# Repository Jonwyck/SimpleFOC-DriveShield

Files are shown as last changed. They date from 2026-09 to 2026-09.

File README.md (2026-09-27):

> Fork additions: [v1.8 pinout and jumper guide](Design/DriveShield_pinout.org), [HTML guide](Design/DriveShield_pinout.html), and [initial KiCad 10 import](KiCad/README.org). The KiCad copy needs ERC/DRC and library/linkage cleanup before fabrication. Original EasyEDA design files remain unchanged.

# *Simple**FOC*** ***Drive**Shield* *v1.8*

 
 



This is an open-source low-cost BLDC driver boards in the form of a Arduino shield. It is a part of the *Simple**FOC*** project. The board is the big brother of the *Simple**FOC**Shield* and is designed to drive motors with higher current requirements, up to 40Amps. The board is created with the same philosophy as the *Simple**FOC**Shield* - to be simple to use, low-cost, and open-source and fully compatible with the *Simple**FOC***library. 

Additionally the aim of the board is to serve as a template project for the community to build their own motor drivers. 
- The board is relatively simple and can be easily modified to fit different requirements.
- The board is designed in EasyEDA and all the fabrication files are available for download

📢 NEW: This board is now available in our collaboration with **Makerfabs**: [See more on makerfabs.com](https://www.makerfabs.com/simplefoc-driveshield.html)

### Components
- **DRV8320H** gate driver - [datahseet](https://www.ti.com/lit/ds/symlink/drv8320.pdf?ts=178671431434)
   - Hardware configuration 
   - 3PWM 
   - Protections: undervoltage lockout, charge pump fault, MOSFET overcurrent, MOSFET short circuit, gate driver fault and overtemperature
- **BSZ0904NSI** mosfets
   - Standard 3mm x 3mm footprint (can be easily exchanged)
   - Max current 75A 
   - Max voltage 30V
- **INA240A1**: - [datasheet](https://www.ti.com/lit/ds/symlink/ina240.pdf?ts=1786684614540)
   - Inline current sensor
   - Gain 20V/V
   - Shunt resistor: 2mΩ (parallel of 4mΩ)
   - 40A measurement range bidirectional (at 3.3V)
- **LM7808**:
   - 8V LDO voltage regulator to VIN 

### Features
- **Boards absolute max ratings** 
   - Max current: 20A continuous (peak 30A - measured) 
   - Max input voltage: 30V
- **Stackable**: running 2 motors in the same time
- **Encoder/Hall sensors interface**: Integrated 3.3kΩ pullups (configurable)
- **I2C interface**: Integrated 4.7kΩ pullups (configurable)
- **Configurable pinout**: Hardware configuration - soldering connections
- **stemma QT connector**: for easy connection of sensors and peripherals
- **JST SPI connector**: for easy connection of SPI devices (only one SPI device can be connected at a time)
- **Arduino headers**: Arduino UNO, Arduino MEGA, STM32 Nucleo boards...
- **Open Source**: 
   - Fully designed in **EasyEDA**: [EasyEDA project](https://oshwlab.com/the.skuric/SimpleFOC-Drive)
   - Fully available fabrication files - [how to make it yourself](https://docs.simplefoc.com/arduino_simplefoc_shield_fabrication)
- **Low-cost**: Estimated price of 25€ - See more in [our shop](https://simplefoc.com/shop)

## Shield version comparison

Feature | <span class="simple">Simple<span class="foc">FOC</span>Shield</span> v1.x | <span class="simple">Simple<span class="foc">FOC</span>Shield</span> v2.x | <span class="simple">Simple<span class="foc">FOC</span>Shield</span> v3.x | <span class="simple">Simple<span class="foc">FOC</span> <b>Drive</b>Shield</span> v1.x
|-|-|-|-|-|
|||||
**PWM Driver** | [L6234](https://www.st.com/resource/en/datasheet/l6234.pdf) | [L6234](https://www.st.com/resource/en/datasheet/l6234.pdf) | [DRV8313](https://www.ti.com/lit/ds/symlink/drv8313.pdf?ts=1719165774986&ref_url=https%253A%252F%252Fwww.google.com%252F)| gate driver: [DRV8320H](https://www.ti.com/lit/ds/symlink/drv8320.pdf) <br> mosfets: [BSZ0904NSI](https://www.infineon.com/dgdl/Infineon-BSZ0904NSI-DataSheet-v02_04-EN.pdf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)
**Current Sense** | ❌ | [INA240](https://www.ti.com/lit/ds/symlink/ina240.pdf?ts=1719180172738) | [ACS712 (5A)](https://www.allegromicro.com/en/products/sense/current-sensor-ics/zero-to-fifty-amp-integrated-conductor-sensor-ics/acs712) | [INA240](https://www.ti.com/lit/ds/symlink/ina240.pdf?ts=1719180172738)
**Current measurement range** | ❌ | (configurable) ±3.3/5Amps | ±5Amps | ±40Amps
**Onboard LDO** | ❌ | LM7808 | LM7808 | LM7808 (v1.8+)
**Stackable** | ✔️ | ✔️ | ✔️ | ✔️
**Max current** | 2Amps (5Amp peak) | 2Amps (5Amp peak) | 2Amps (3Amp peak) | 20Amps (40Amp peak)
**Max voltage** | 24V | 35V | 35V | 30V 
**Protections** | Overtemperature | Overtemperature | Overtemperature, Overcurrent | undervoltage lockout, charge pump fault, MOSFET overcurrent, MOSFET short circuit, gate driver fault, overtemperature
**Footprint** | 68mm x 53 mm | 68mm x 53 mm | 56mm x 53mm | 56mm x 53mm
**Design tool** | Altium Designer 2019 | Altium Designer 2019 | EasyEDA | EasyEDA 

## Board evolution timeline

To check the release timeline, click [here](https://github.com/simplefoc/SimpleFOC-driveShield/releases) 

Version  | release | Release date | Comment
----- | ----- | ---- | ----
*Simple**FOC** **Drive**Shield* v1.0 | v0.1 | 05/24 | - Test version <br> - **DRV8300** gate driver <br> - **SE3082G** dual mosfets <br> - ACS712 (range +-30Amps) <br> - 20V max voltage 
*Simple**FOC** **Drive**Shield* v1.0 | v1.0 | 06/24 | - Transition to **DRV8320H** gate driver <br>  - 30V max voltage
*Simple**FOC** **Drive**Shield* v1.1 | v1.1 | 07/24 | - Transition to 3x3mm **BSZ09x** mosfets instead of **SE3082G** <br> - 30V max voltage
*Simple**FOC** **Drive**Shield* v1.2 | [v1.2](https://github.com/simplefoc/SimpleFOC-DriveShield/releases/tag/v1.2) | 08/24 | Initial release <br>- Transition to **4 layer** PCB <br> - Enabling stacking (soldering pads) <br> - Configurable pullups (I2C and encoder) 
*Simple**FOC** **Drive**Shield* v1.7 | v1.7 | 02/26 | - stemma QT connector<br>-SPI connector<br>- INA240 current sensing <br>- Power supply measurement
*Simple**FOC** **Drive**Shield* v1.8 | v1.8 | 06/26 | - added LDO to power the board from VIN (8V) 

## Size comparison with SimpleFOCShield v3



## Temperature characteristics study

This board can measure the phase currents up to 30Amps, so it is intended to be used in applications that require current draw up to around 20Amps continuous. For higher currents especially in the range of 15-30Amps the board can get quite hot. Depending on the copper thickness of the PCB chosen when ordering the board the temperature can vary, as well as the cooling conditions. The board can be fitted with a heatsink to improve the thermal performance.

So I've wanted to quantify the temperature characteristics of the board when a continuous current is applied to the motor. The measurements were done with a relatively constant ambient temperature of around 25°C. The board was powered with 24V. The motor was run at very low speed (0.1rad/s) in the open loop and the current (q component) was set to 10, 15 and 20 amps for prolonged periods of time. I've measured the temperature on the top of the board on the DRV8320H gate driver and the BSZ0904NSI mosfets. I've used the PICOLOG TC-08 thermocouple data logger to do the measuring.

Two copper thicknesses were tested
1. Standard 4-layer: 
    - **1oz** (35um) copper thickness on top and bottom layers, 
    - **0.5oz** (17.5um) copper thickness on inner layers



2. Thick 4-layer: 
    - **2oz** (70um) copper thickness on top and bottom layers, 
    - **0.5oz** (35um) copper thickness on inner layers



### Experiment results
Here is the table of the results

Current [A] | Standard 4-layer MOSFETS | Thick 4-layer  MOSFETS | Standard 4-layer DRV8320 |  Thick 4-layer DRV8320 
--- | --- | ---| --- | ---
10 | 57°C| 53°C | 50°C  | 52°C
15 | 78°C | 68°C| 62°C  | 62°C
20 | 125°C  | 100°C | 82°C | 82°C

So the results seem to suggest that, as the **BSZ0904NSI** mosfets are rated for temperatures up to 150°C and the **DRV8320H** gate driver up to 125°C, the board can be used up to 20Amps without additional cooling. 

**However, I would definitely recommend using a heatsink or a thicker copper PCB (2oz top and bottom layers) for currents above 15Amps continuous.**

<details>
<summary>Measured temperatures during the experiment</summary>



</details>

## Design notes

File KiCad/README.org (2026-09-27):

#+TITLE: DriveShield v1.8 initial native KiCad import
#+DATE: 2026-09-27

Open DriveShield_v1_8.kicad_pro in KiCad 10.0.1 or later.

This is an inspection/migration copy of the unchanged upstream EasyEDA design, not a fabrication release. Read ../Design/DriveShield_pinout.org (or its HTML export) before using it.

* Validation
- Schematic loaded in the native editor and exported to PDF and XML netlist.
- PCB imported with the native EasyEDA Standard importer; importer reports zero errors/warnings.
- All 301 source pad instances, including standalone pads, retain their pad number and net name in the imported PCB (pad-net-audit.json).
- ERC: 439 findings. Schematic references, pin electrical types, library assignments and dangling source labels need work.
- PCB DRC completed outside the sandbox: 1322 findings, including 862 errors and 460 warnings; zero unconnected items. Zero unconnected items does not establish schematic/PCB parity.
- Footprints and schematic symbols have not been reconciled for safe Update PCB from Schematic.
- Original circuit and original source files were not modified.

* Reproduction
- Source commit: 22b4c5506e67aa473017a09c13aa4fd4a453504b.
- PCB: kicad-cli pcb import ../EasyEDA/PCB_pcb_drive_2026-08-14.json --output DriveShield_v1_8.kicad_pcb.
- Schematic: in standalone Schematic Editor, File > Import > Non-KiCad Schematic; select ../EasyEDA/SCH_SimpleFOC-Drive_2026-08-14.json; save as DriveShield_v1_8.kicad_sch in this directory.
- Import creates embedded schematic symbols; shared symbol/footprint libraries still require migration work.

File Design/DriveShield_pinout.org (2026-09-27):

#+TITLE: SimpleFOC DriveShield v1.8 — Pinout and KiCad import
#+DATE: 2026-09-27
#+OPTIONS: toc:2 num:nil
#+HTML_HEAD: <style>body{font:16px/1.6 system-ui,sans-serif;max-width:1100px;margin:auto;padding:2em;color:#183047}table{border-collapse:collapse;width:100%;margin:1em 0}th,td{border:1px solid #9cabb5;padding:.5em;text-align:left}th{background:#edf3f7}img{max-width:100%;height:auto}code{background:#eef2f5;padding:.15em}a{color:#075fa6}h2{margin-top:2em}.figure{margin:1.5em 0}</style>

* Source and status

- Original repository: https://github.com/simplefoc/SimpleFOC-DriveShield
- Fork: https://github.com/Jonwyck/SimpleFOC-DriveShield
- Reviewed upstream commit: =22b4c5506e67aa473017a09c13aa4fd4a453504b=.
- Source files: =EasyEDA/PCB_pcb_drive_2026-08-14.json= and =EasyEDA/SCH_SimpleFOC-Drive_2026-08-14.json=.
- Pinout below was checked against the PCB pad nets and schematic. Solder selections are configurable; no factory jumper population is assumed.
- Initial native KiCad 10.0.1 import is in =../KiCad/=. It is for inspection and migration work, not yet a fabrication release. No circuit modification has been applied.

* Practical 3-PWM connection

The board accepts logic-level switching PWM, not an RC/servo throttle command. Its stock configuration is 3-PWM: one input controls each complementary half-bridge. The signal called =ENABLE= connects to U2 pin 22 and all three INL inputs.

The following is a proposed solder-jumper selection for a bench adapter, not a claim about the delivered board's default bridges. All connector pin numbers are physical pad numbers from the PCB file; =D5=, etc. are Arduino signal names.

| Function | Arduino signal | Physical connector pin | Board connection / selection |
|----------+----------------+------------------------+------------------------------|
| PWM for output M1 | D5 | P1.3 | Bridge INC / INHC to 5; alternative D3 / P1.5 |
| PWM for output M2 | D9 | P2.9 | Bridge INB / INHB to 9; alternative D10 / P2.8 |
| PWM for output M3 | D6 | P1.2 | Bridge INA / INHA to 6; alternatives D11 / P2.7 or D13 / P2.5 |
| Enable | D8 | P2.10 | Bridge EN to 8; alternative D7 / P1.1 |
| Current at M1 | A0 | P3.1 | Bridge CS1 / C2_OUT to A0; alternative A1 / P3.2 |
| Current at M3 | A2 | P3.3 | Bridge CS3 / C1_OUT to A2; alternative A3 / P3.4 |
| Fault return, active LOW | A3 | P3.4 | Close nFLT-to-A3 bridge; reserve A3 for this signal |
| DC-link voltage / 11 | A4 | P3.5 | Bridge VCC/11 to A4; alternative A3 / P3.4 |
| Local logic supply | 3.3 V | P4.4 | Supply 3.3 V referenced to board GND; select 3.3 V-to-VDD bridge |
| Local signal ground | GND | P4.6 or P4.7; also P2.4 | Same electrical ground as DC-bus negative |
| DC-bus positive | VCC / PWR | Large PWR terminal | Planned 12 V link; use this power terminal |
| DC-bus negative | GND | Large GND terminal | Power return |

*Do not close several competing bridges to the same header pin.* A3 can receive fault, M3 current, or bus voltage. The proposal above uses A3 only for fault and A4 for bus voltage; leave the encoder-to-A4 bridge open. Selecting PWM on D11/D13 also conflicts with the SPI connector signals.

The 3.3 V signal supply and its isolation barrier must be on the power-stage side of the interface. Directly connecting an SST MCU ground to this board would defeat the requested controller-to-power-stage isolation. The onboard 8 V regulator supplies the Arduino VIN rail only when its enable bridge is closed; VIN is not the main DC-bus input, and it does not itself supply the required 3.3 V VDD rail.

** Why M1 is not phase A

| Power terminal | Driver phase | Driver PWM input | Inline current signal |
|----------------+--------------+------------------+-----------------------|
| M1 | C | INHC, U2.29 | U5 output C2_OUT; board silk CS1 |
| M2 | B | INHB, U2.27 | No fitted inline current sensor |
| M3 | A | INHA, U2.25 | U1 output C1_OUT; board silk CS3 |

Both fitted current channels have two parallel 4 mΩ shunts (effective 2 mΩ) and INA240A1 gain 20: sensitivity = 0.040 V/A. With VDD = 3.3 V, nominal output is =1.65 V + 0.040 × I=, where positive current flows out of the half-bridge toward the M1 or M3 terminal. This is a transfer equation, not a guarantee of rail-to-rail measurement range. The two channels are nonisolated.

The voltage divider is 47 kΩ over 4.7 kΩ, so =Vout = Vbus / 11=. Despite the net name =0.1_VCC=, its ratio is 1/11, not 1/10. For a 12 V link the nominal feedback is 1.091 V.

** Header numbering

Use the square pad to identify physical pin 1. Do not count pins from the wrong board side. The complete pad/net list is [[file:header-pins.csv][header-pins.csv]].

| Header | Physical pin sequence |
|--------+-----------------------|
| P1, pins 1–8 | D7, D6, D5, D4, D3, D2, unused D1 position, unused D0 position |
| P2, pins 1–10 | SCL, SDA, unused AREF position, GND, D13, D12, D11, D10, D9, D8 |
| P3, pins 1–6 | A0, A1, A2, A3, A4, A5 |
| P4, pins 1–8 | unused, unused IOREF position, unused RESET position, 3.3 V, 5 V, GND, GND, VIN |

The unused positions above have no functional route in this PCB. They should not be assumed to provide reset, UART or reference functions merely because they occupy Arduino header positions.

** Auxiliary connectors

| Connector | Physical pin sequence | Notes |
|-----------+-----------------------+-------|
| CN1, SPI, pins 1–6 | GND, VDD, D11/MOSI, D12/MISO, D13/SCK, D4/CS | External peripheral connector, not an SPI configuration port for DRV8320H |
| CN2, I2C, pins 1–4 | GND, VDD, SDA, SCL | Pull-ups are selectable |
| P_ENC1, pins 1–5 | ENC_A, ENC_B, ENC_I, GND, VDD | Encoder input signals use selectable bridges |

CN1 pads 7/8 and CN2 pads 5/6 are grounded mounting tabs, not extra cable contacts. Encoder assignments: ENC_A → D3/D12/A4; ENC_B → D2/A5; ENC_I → D4/D11/D13. Select only the routes needed and check PWM/SPI/analog conflicts.

* PCB location drawings

These plots come from the imported v1.8 PCB geometry. Pads and original silk are shown. They are useful for locating the jumper groups; they do not prove the solder population on a purchased board.

#+CAPTION: Component side, top view. Match the VCC/GND and M1/M2/M3 power terminals and the square header pads before counting connector pins.
#+ATTR_HTML: :width 1000
[[file:pcb-top.svg]]

#+CAPTION: Solder side, viewed from underneath (mirrored relative to the top view). Locate INA/INB/INC, EN, CS1/CS3, nFLT, VCC/11, and VDD config. Selecting a signal means bridging its centre signal pad to one chosen labelled header pad.
#+ATTR_HTML: :width 1000
[[file:pcb-bottom.svg]]

* What changes are needed for six independent PWM inputs

The existing headers do not expose six independent gate-command inputs. The AH/AL/BH/BL/CH/CL test points are MOSFET gate-drive outputs; never feed controller PWM into those points.

| Item | Stock circuit | Required for 6-PWM |
|------+---------------+--------------------|
| R10 / MODE, U2.18 | 47 kΩ to GND selects 3-PWM | 0 Ω to GND selects 6-PWM |
| INHA, U2.25 | Selected header PWM for phase A / M3 | Keep independent high-side command |
| INLA, U2.26 | Connected to ENABLE | Separate from ENABLE; route independent low-side command |
| INHB, U2.27 | Selected header PWM for phase B / M2 | Keep independent high-side command |
| INLB, U2.28 | Connected to ENABLE | Separate from ENABLE; route independent low-side command |
| INHC, U2.29 | Selected header PWM for phase C / M1 | Keep independent high-side command |
| INLC, U2.30 | Connected to ENABLE | Separate from ENABLE; route independent low-side command |
| ENABLE, U2.22 | Common board enable | Retain separate enable with a defined LOW shutdown state |

This is a functional conversion description, not a validated trace-cut instruction. Confirm exact routing on the delivered revision before modifying it. External 300 ns deadtime can then be commanded; measure actual high-side and low-side VGS timing after the driver and isolation interface. In stock 3-PWM mode, PWM LOW with ENABLE HIGH turns the low-side MOSFET on. Deassert ENABLE to disable the board.

The hardware driver has a charge pump supporting continuous high-side ON. Its PWM input specification covers 50 kHz, but the assembled board needs thermal and switching-waveform validation at the intended resonant current. Preserve the common DC-bus topology: all three half-bridges on one board share VCC and GND.

* KiCad conversion and validation status

Open [[file:../KiCad/DriveShield_v1_8.kicad_pro][DriveShield_v1_8.kicad_pro]] with KiCad 10.0.1 or later. The schematic and PCB were imported with KiCad's native EasyEDA Standard importers. No third-party converter was needed.

The PCB import report lists 112 footprints, 420 tracks, 442 vias and 29 zones, with four copper layers and no reported import errors or warnings. Standalone jumper/test pads are represented as additional footprints. The schematic can be exported to [[file:../KiCad/DriveShield_v1_8.pdf][PDF]].

The read-only [[file:../KiCad/pad-net-audit.json][pad/net audit]] compares each original component pad and standalone pad with the imported PCB. Its scope is pad numbering and net assignment, not proof of physical copper connectivity or schematic/PCB parity.

Remaining migration work:

1. Reconcile schematic references =U1.1/U5.1= with PCB =U1/U5=, and references without the numbering convention expected by KiCad.
2. Extract/register symbol and footprint libraries, assign schematic footprint identifiers, and link schematic symbols to existing PCB footprints. Imported symbols are embedded, but a complete reusable library setup is not established.
3. Represent the source's physical solder-selection pads explicitly in the schematic. Many source configuration blocks are just unattached net labels; KiCad consequently reports dangling labels.
4. Resolve ERC findings. Initial ERC reports 439 findings: many are unspecified pin types, missing library associations, off-grid endpoints, and source dangling labels. This is not an ERC pass.
5. Resolve PCB DRC and zone validation. Retrying the initial sandbox-aborted check outside the sandbox completed: 1,322 findings (862 errors, 460 warnings), with zero unconnected items. Findings include clearance, hole spacing, padstack, outline and intersecting-zone issues. Some may require restoring original design rules or repairing imported geometry; their causes have not all been resolved. This is not a DRC pass. See =../KiCad/drc.json=.
6. Reconcile schematic/PCB differences before using “Update PCB from Schematic”; do not apply a bulk update to this preliminary import.

The published BOM also retains documentation inconsistencies: 16 V C0603B104K160NT parts are listed at bus bypass positions despite the 30 V advertised maximum, and the MOSFET row's Name and Manufacturer Part fields differ. Verify fitted parts before increasing the bus voltage or releasing a derivative design.

** References

- [[https://docs.kicad.org/10.0/en/eeschema/eeschema.html][KiCad 10 Schematic Editor: EasyEDA import and post-import checks]]
- [[https://dev-docs.kicad.org/en/import-formats/easyeda/index.html][KiCad EasyEDA format documentation]]
- [[https://www.ti.com/lit/ds/symlink/drv8320.pdf][DRV832x datasheet: mode truth tables, charge pump, timing and input levels]]
- [[https://www.ti.com/lit/ds/symlink/ina240.pdf][INA240 datasheet]]

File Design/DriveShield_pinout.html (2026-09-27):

# SimpleFOC DriveShield v1.8 — Pinout and KiCad import

## Table of Contents

- Source and status
- Practical 3-PWM connection
  - Why M1 is not phase A
  - Header numbering
  - Auxiliary connectors
- PCB location drawings
- What changes are needed for six independent PWM inputs
- KiCad conversion and validation status
  - References

## Source and status

- Original repository: https://github.com/simplefoc/SimpleFOC-DriveShield
- Fork: https://github.com/Jonwyck/SimpleFOC-DriveShield
- Reviewed upstream commit: 22b4c5506e67aa473017a09c13aa4fd4a453504b.
- Source files: EasyEDA/PCB_pcb_drive_2026-08-14.json and EasyEDA/SCH_SimpleFOC-Drive_2026-08-14.json.
- Pinout below was checked against the PCB pad nets and schematic. Solder selections are configurable; no factory jumper population is assumed.
- Initial native KiCad 10.0.1 import is in ../KiCad/. It is for inspection and migration work, not yet a fabrication release. No circuit modification has been applied.

## Practical 3-PWM connection

The board accepts logic-level switching PWM, not an RC/servo throttle command. Its stock configuration is 3-PWM: one input controls each complementary half-bridge. The signal called ENABLE connects to U2 pin 22 and all three INL inputs.

The following is a proposed solder-jumper selection for a bench adapter, not a claim about the delivered board's default bridges. All connector pin numbers are physical pad numbers from the PCB file; D5, etc. are Arduino signal names.

Function | Arduino signal | Physical connector pin | Board connection / selection
PWM for output M1 | D5 | P1.3 | Bridge INC / INHC to 5; alternative D3 / P1.5
PWM for output M2 | D9 | P2.9 | Bridge INB / INHB to 9; alternative D10 / P2.8
PWM for output M3 | D6 | P1.2 | Bridge INA / INHA to 6; alternatives D11 / P2.7 or D13 / P2.5
Enable | D8 | P2.10 | Bridge EN to 8; alternative D7 / P1.1
Current at M1 | A0 | P3.1 | Bridge CS1 / C2OUT to A0; alternative A1 / P3.2
Current at M3 | A2 | P3.3 | Bridge CS3 / C1OUT to A2; alternative A3 / P3.4
Fault return, active LOW | A3 | P3.4 | Close nFLT-to-A3 bridge; reserve A3 for this signal
DC-link voltage / 11 | A4 | P3.5 | Bridge VCC/11 to A4; alternative A3 / P3.4
Local logic supply | 3.3 V | P4.4 | Supply 3.3 V referenced to board GND; select 3.3 V-to-VDD bridge
Local signal ground | GND | P4.6 or P4.7; also P2.4 | Same electrical ground as DC-bus negative
DC-bus positive | VCC / PWR | Large PWR terminal | Planned 12 V link; use this power terminal
DC-bus negative | GND | Large GND terminal | Power return

Do not close several competing bridges to the same header pin. A3 can receive fault, M3 current, or bus voltage. The proposal above uses A3 only for fault and A4 for bus voltage; leave the encoder-to-A4 bridge open. Selecting PWM on D11/D13 also conflicts with the SPI connector signals.

The 3.3 V signal supply and its isolation barrier must be on the power-stage side of the interface. Directly connecting an SST MCU ground to this board would defeat the requested controller-to-power-stage isolation. The onboard 8 V regulator supplies the Arduino VIN rail only when its enable bridge is closed; VIN is not the main DC-bus input, and it does not itself supply the required 3.3 V VDD rail.

### Why M1 is not phase A

Power terminal | Driver phase | Driver PWM input | Inline current signal
M1 | C | INHC, U2.29 | U5 output C2OUT; board silk CS1
M2 | B | INHB, U2.27 | No fitted inline current sensor
M3 | A | INHA, U2.25 | U1 output C1OUT; board silk CS3

Both fitted current channels have two parallel 4 mΩ shunts (effective 2 mΩ) and INA240A1 gain 20: sensitivity = 0.040 V/A. With VDD = 3.3 V, nominal output is 1.65 V + 0.040 × I, where positive current flows out of the half-bridge toward the M1 or M3 terminal. This is a transfer equation, not a guarantee of rail-to-rail measurement range. The two channels are nonisolated.

The voltage divider is 47 kΩ over 4.7 kΩ, so Vout = Vbus / 11. Despite the net name 0.1_VCC, its ratio is 1/11, not 1/10. For a 12 V link the nominal feedback is 1.091 V.

### Header numbering

Use the square pad to identify physical pin 1. Do not count pins from the wrong board side. The complete pad/net list is header-pins.csv.

Header | Physical pin sequence
P1, pins 1–8 | D7, D6, D5, D4, D3, D2, unused D1 position, unused D0 position
P2, pins 1–10 | SCL, SDA, unused AREF position, GND, D13, D12, D11, D10, D9, D8
P3, pins 1–6 | A0, A1, A2, A3, A4, A5
P4, pins 1–8 | unused, unused IOREF position, unused RESET position, 3.3 V, 5 V, GND, GND, VIN

The unused positions above have no functional route in this PCB. They should not be assumed to provide reset, UART or reference functions merely because they occupy Arduino header positions.

### Auxiliary connectors

Connector | Physical pin sequence | Notes
CN1, SPI, pins 1–6 | GND, VDD, D11/MOSI, D12/MISO, D13/SCK, D4/CS | External peripheral connector, not an SPI configuration port for DRV8320H
CN2, I2C, pins 1–4 | GND, VDD, SDA, SCL | Pull-ups are selectable
PENC1, pins 1–5 | ENCA, ENCB, ENCI, GND, VDD | Encoder input signals use selectable bridges

CN1 pads 7/8 and CN2 pads 5/6 are grounded mounting tabs, not extra cable contacts. Encoder assignments: ENCA → D3/D12/A4; ENCB → D2/A5; ENCI → D4/D11/D13. Select only the routes needed and check PWM/SPI/analog conflicts.

## PCB location drawings

These plots come from the imported v1.8 PCB geometry. Pads and original silk are shown. They are useful for locating the jumper groups; they do not prove the solder population on a purchased board.



Figure 1: Component side, top view. Match the VCC/GND and M1/M2/M3 power terminals and the square header pads before counting connector pins.



Figure 2: Solder side, viewed from underneath (mirrored relative to the top view). Locate INA/INB/INC, EN, CS1/CS3, nFLT, VCC/11, and VDD config. Selecting a signal means bridging its centre signal pad to one chosen labelled header pad.

## What changes are needed for six independent PWM inputs

The existing headers do not expose six independent gate-command inputs. The AH/AL/BH/BL/CH/CL test points are MOSFET gate-drive outputs; never feed controller PWM into those points.

Item | Stock circuit | Required for 6-PWM
R10 / MODE, U2.18 | 47 kΩ to GND selects 3-PWM | 0 Ω to GND selects 6-PWM
INHA, U2.25 | Selected header PWM for phase A / M3 | Keep independent high-side command
INLA, U2.26 | Connected to ENABLE | Separate from ENABLE; route independent low-side command
INHB, U2.27 | Selected header PWM for phase B / M2 | Keep independent high-side command
INLB, U2.28 | Connected to ENABLE | Separate from ENABLE; route independent low-side command
INHC, U2.29 | Selected header PWM for phase C / M1 | Keep independent high-side command
INLC, U2.30 | Connected to ENABLE | Separate from ENABLE; route independent low-side command
ENABLE, U2.22 | Common board enable | Retain separate enable with a defined LOW shutdown state

This is a functional conversion description, not a validated trace-cut instruction. Confirm exact routing on the delivered revision before modifying it. External 300 ns deadtime can then be commanded; measure actual high-side and low-side VGS timing after the driver and isolation interface. In stock 3-PWM mode, PWM LOW with ENABLE HIGH turns the low-side MOSFET on. Deassert ENABLE to disable the board.

The hardware driver has a charge pump supporting continuous high-side ON. Its PWM input specification covers 50 kHz, but the assembled board needs thermal and switching-waveform validation at the intended resonant current. Preserve the common DC-bus topology: all three half-bridges on one board share VCC and GND.

## KiCad conversion and validation status

Open DriveShieldv18.kicadpro with KiCad 10.0.1 or later. The schematic and PCB were imported with KiCad's native EasyEDA Standard importers. No third-party converter was needed.

The PCB import report lists 112 footprints, 420 tracks, 442 vias and 29 zones, with four copper layers and no reported import errors or warnings. Standalone jumper/test pads are represented as additional footprints. The schematic can be exported to PDF.

The read-only pad/net audit compares each original component pad and standalone pad with the imported PCB. Its scope is pad numbering and net assignment, not proof of physical copper connectivity or schematic/PCB parity.

Remaining migration work:

1. Reconcile schematic references U1.1/U5.1 with PCB U1/U5, and references without the numbering convention expected by KiCad.
2. Extract/register symbol and footprint libraries, assign schematic footprint identifiers, and link schematic symbols to existing PCB footprints. Imported symbols are embedded, but a complete reusable library setup is not established.
3. Represent the source's physical solder-selection pads explicitly in the schematic. Many source configuration blocks are just unattached net labels; KiCad consequently reports dangling labels.
4. Resolve ERC findings. Initial ERC reports 439 findings: many are unspecified pin types, missing library associations, off-grid endpoints, and source dangling labels. This is not an ERC pass.
5. Resolve PCB DRC and zone validation. Retrying the initial sandbox-aborted check outside the sandbox completed: 1,322 findings (862 errors, 460 warnings), with zero unconnected items. Findings include clearance, hole spacing, padstack, outline and intersecting-zone issues. Some may require restoring original design rules or repairing imported geometry; their causes have not all been resolved. This is not a DRC pass. See ../KiCad/drc.json.
6. Reconcile schematic/PCB differences before using “Update PCB from Schematic”; do not apply a bulk update to this preliminary import.

The published BOM also retains documentation inconsistencies: 16 V C0603B104K160NT parts are listed at bus bypass positions despite the 30 V advertised maximum, and the MOSFET row's Name and Manufacturer Part fields differ. Verify fitted parts before increasing the bus voltage or releasing a derivative design.

### References

- KiCad 10 Schematic Editor: EasyEDA import and post-import checks (https://docs.kicad.org/10.0/en/eeschema/eeschema.html)
- KiCad EasyEDA format documentation (https://dev-docs.kicad.org/en/import-formats/easyeda/index.html)
- DRV832x datasheet: mode truth tables, charge pump, timing and input levels (https://www.ti.com/lit/ds/symlink/drv8320.pdf)
- INA240 datasheet (https://www.ti.com/lit/ds/symlink/ina240.pdf)

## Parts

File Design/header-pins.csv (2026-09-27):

Connector | Physical pin number | PCB net
CN1 | 1 | GND
CN1 | 2 | VDD
CN1 | 3 | PIN11
CN1 | 4 | PIN12
CN1 | 5 | PIN13
CN1 | 6 | PIN4
CN1 | 7 | GND
CN1 | 8 | GND
CN2 | 1 | GND
CN2 | 2 | VDD
CN2 | 3 | SDA
CN2 | 4 | SCL
CN2 | 5 | GND
CN2 | 6 | GND
P1 | 1 | PIN7
P1 | 2 | PIN6
P1 | 3 | PIN5
P1 | 4 | PIN4
P1 | 5 | PIN3
P1 | 6 | PIN2
P1 | 7 | P1_7
P1 | 8 | P1_8
P2 | 1 | SCL
P2 | 2 | SDA
P2 | 3 | P2_3
P2 | 4 | GND
P2 | 5 | PIN13
P2 | 6 | PIN12
P2 | 7 | PIN11
P2 | 8 | PIN10
P2 | 9 | PIN9
P2 | 10 | PIN8
P3 | 1 | PINA0
P3 | 2 | PINA1
P3 | 3 | PINA2
P3 | 4 | PINA3
P3 | 5 | PINA4
P3 | 6 | PINA5
P4 | 1 | P4_1
P4 | 2 | P4_2
P4 | 3 | P4_3
P4 | 4 | 3.3V
P4 | 5 | +5V
P4 | 6 | GND
P4 | 7 | GND
P4 | 8 | VIN
P_ENC1 | 1 | ENC_A
P_ENC1 | 2 | ENC_B
P_ENC1 | 3 | ENC_I
P_ENC1 | 4 | GND
P_ENC1 | 5 | VDD

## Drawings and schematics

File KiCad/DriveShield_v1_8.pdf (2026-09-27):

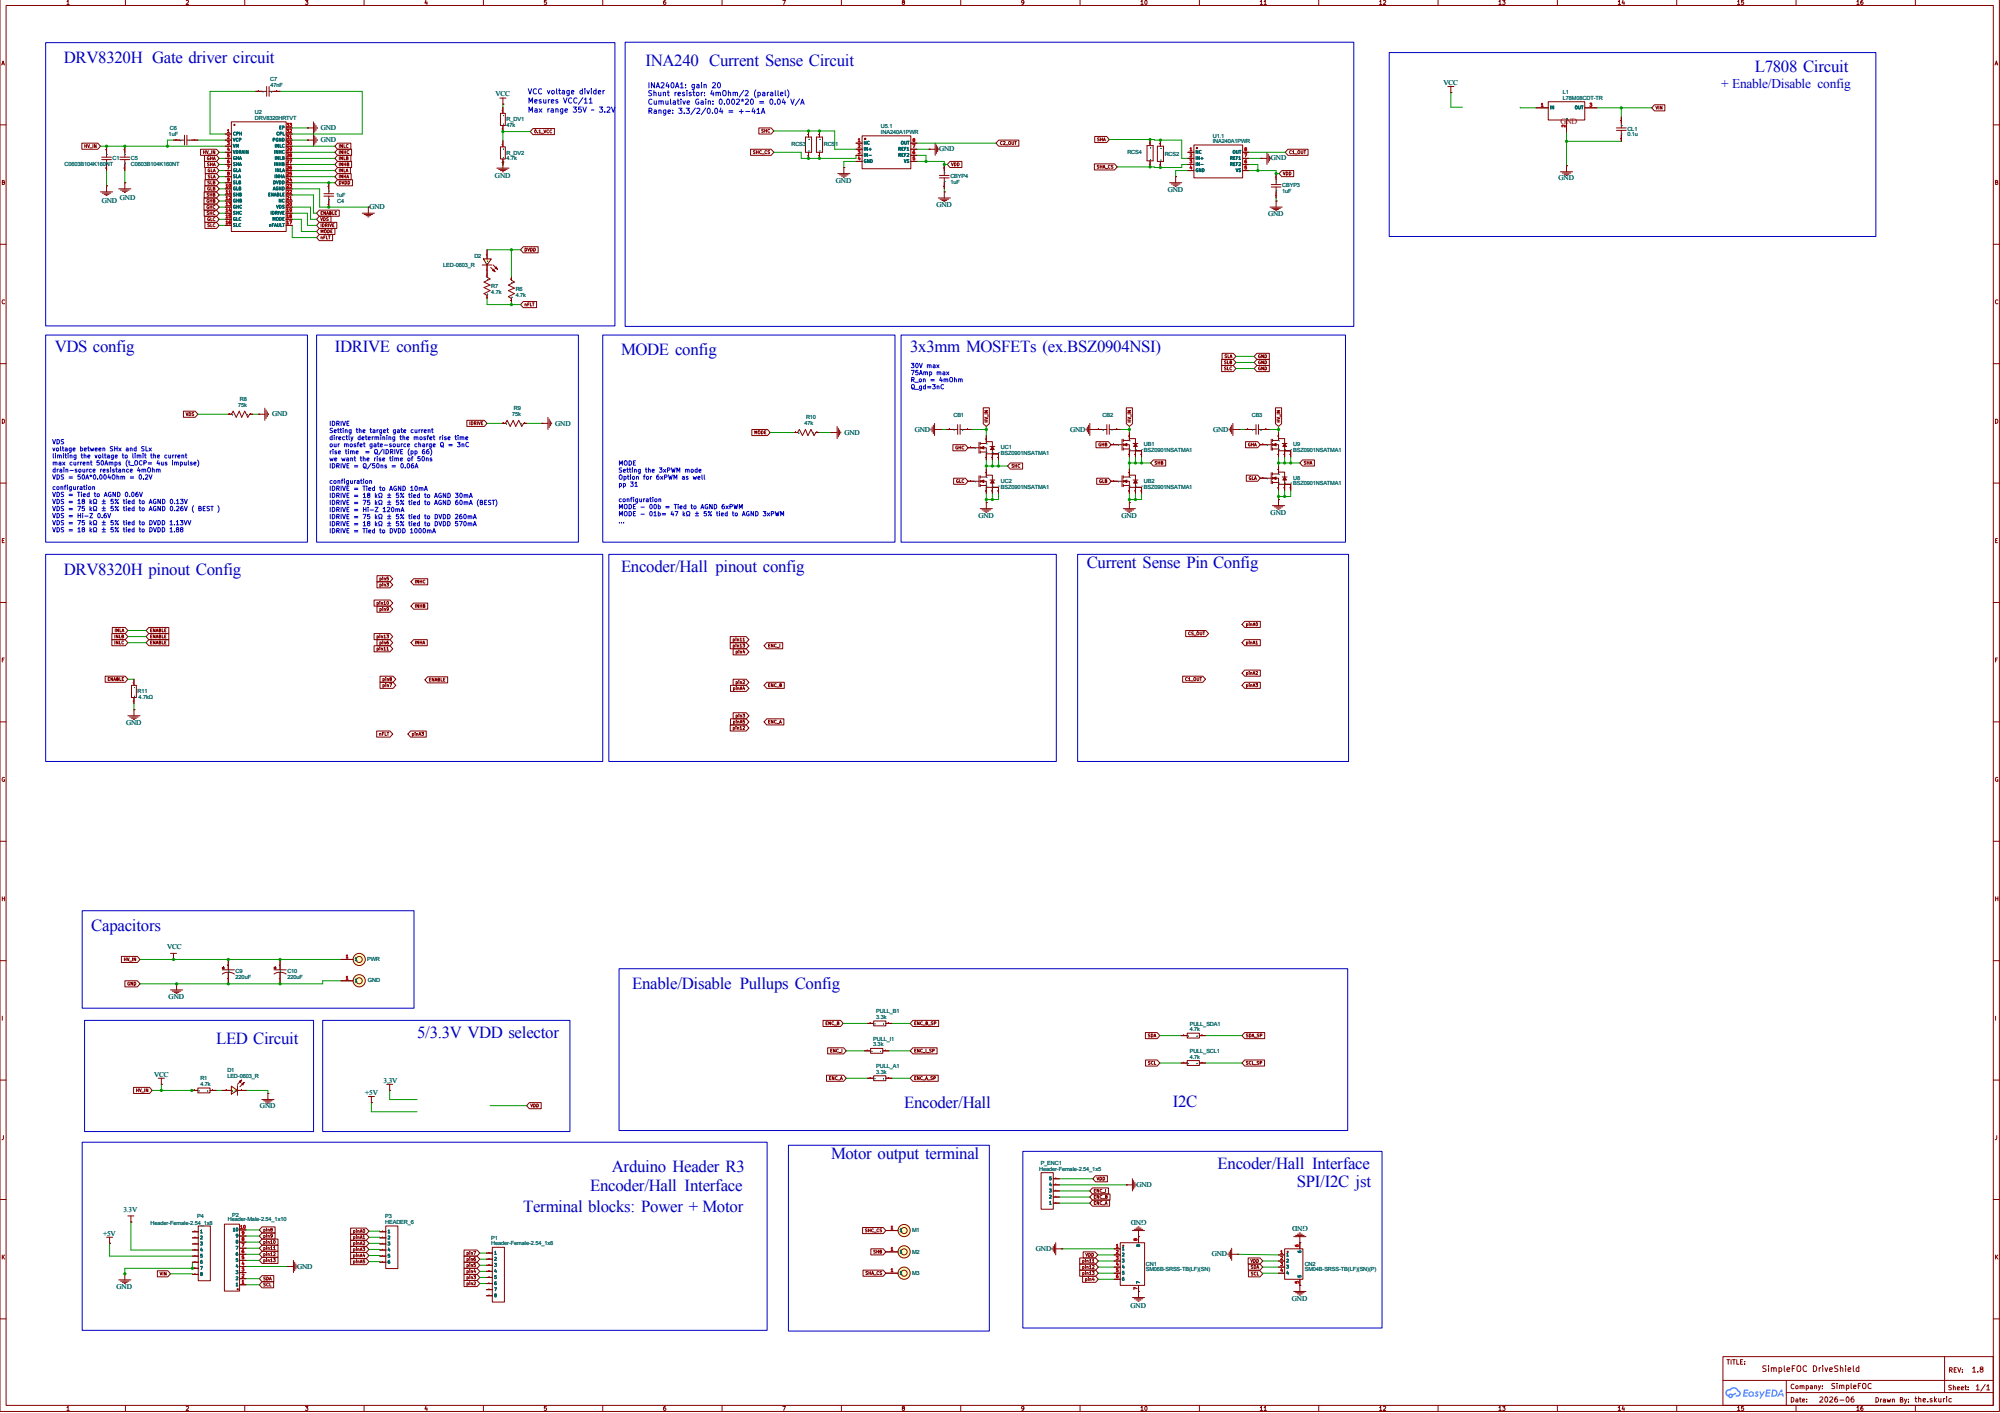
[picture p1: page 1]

SLA GLA SHA GHB

IDRIVE
Setting the target gate current

directly determining the mosfet rise time our mosfet gate-source charge Q = 3nC

VDS
voltage between SHx and SLx

rise time = Q/IDRIVE (pp 66) we want the rise time of 50ns

limiting the voltage to limit the current max current 50Amps (t_OCP= 4us impulse)

... MODE
Setting the 3xPWM mode
Option for 6xPWM as well

configuration
IDRIVE = Tied to AGND 10mA

VDS = Tied to AGND 0.06V
VDS = 18 kΩ ± 5% tied to AGND 0.13V
VDS = 75 kΩ ± 5% tied to AGND 0.26V ( BEST )
VDS = Hi-Z 0.6V
VDS = 75 kΩ ± 5% tied to DVDD 1.13VV
VDS = 18 kΩ ± 5% tied to DVDD 1.88
DRV8320H pinout Config

IDRIVE = 18 kΩ ± 5% tied to AGND 30mA
IDRIVE = 75 kΩ ± 5% tied to AGND 60mA (BEST)
IDRIVE = Hi-Z 120mA
IDRIVE = 75 kΩ ± 5% tied to DVDD 260mA
IDRIVE = 18 kΩ ± 5% tied to DVDD 570mA
IDRIVE = Tied to DVDD 1000mA

MODE - 00b = Tied to AGND 6xPWM
MODE - 01b= 47 kΩ ± 5% tied to AGND 3xPWM

Encoder/Hall pinout config

Current Sense Pin Config

Enable/Disable Pullups Config

Terminal blocks: Power + Motor

SM06B-SRSS-TB(LF)(SN)

TITLE: SimpleFOC DriveShield | REV: 1.8

Company: SimpleFOC | 1/1 Sheet:

Drawn By: the.skuric

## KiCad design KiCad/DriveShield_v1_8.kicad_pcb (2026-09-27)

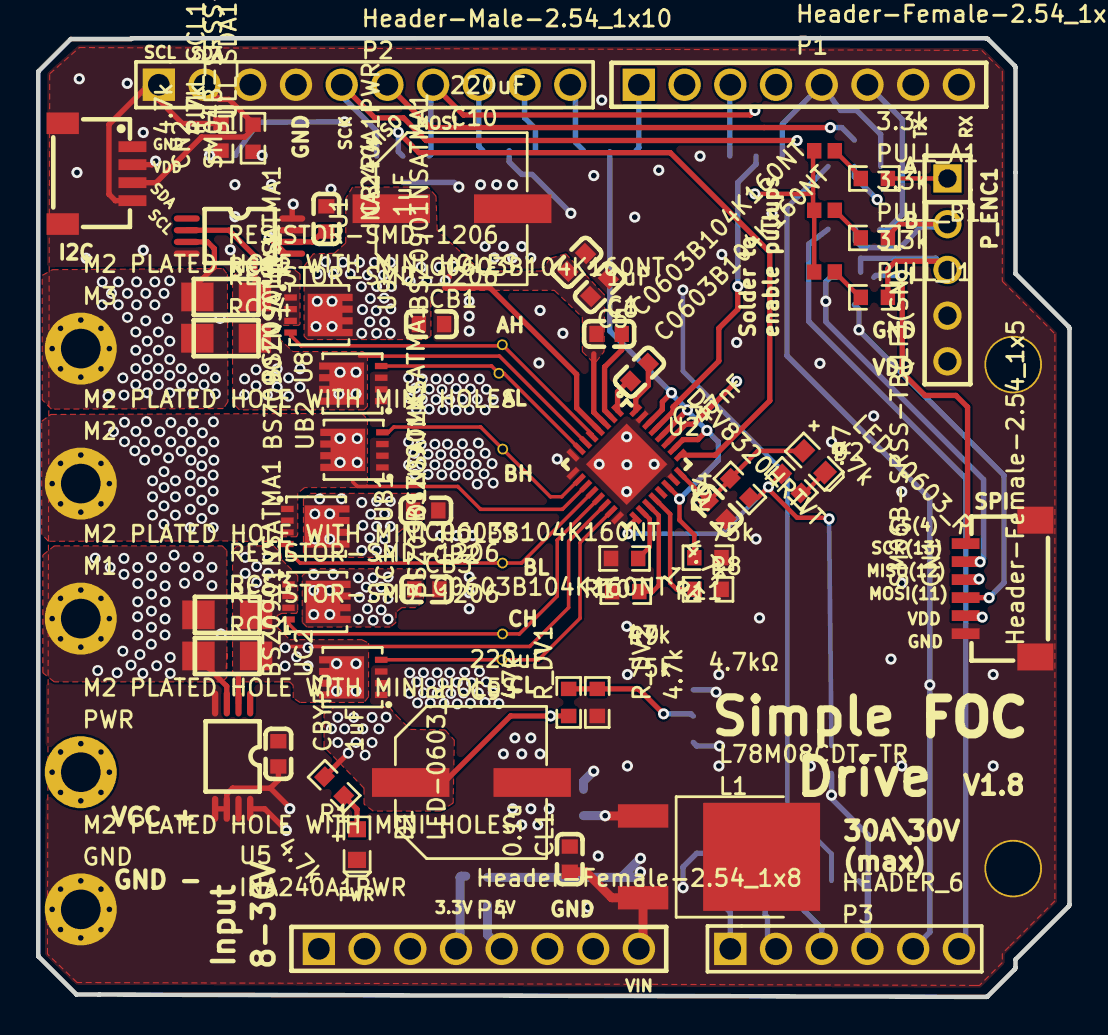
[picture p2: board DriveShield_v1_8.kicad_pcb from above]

Board: 4 copper layers, 57.3 x 53.3 mm, 112 parts (0 on the bottom side), 63 nets.

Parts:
C1, C5: C0603B104K160NT; C0603
C4, C6: 1uF; C0603
C7: 47nF; C0603
C9, C10: 220uF; CAP-SMD_BD8.0-L8.3-W8.3-LS9.5-FD
CB1, CB2, CB3: C0603B104K160NT; C0603
CBYP3, CBYP4: 1uF; C0603
CL1: 0.1u; C0603
CN1: SM06B-SRSS-TB(LF)(SN); CONN-SMD_SM06B-SRSS-TB-LF-SN
CN2: SM04B-SRSS-TB(LF)(SN)(P); CONN-SMD_4P-P1.00_SM04B-SRSS-TB-LF-SN
D1, D2: LED-0603_R; LED0603_RED
GND: M2 PLATED HOLE WITH MINI HOLES
L1: L78M08CDT-TR; TO-252-2_L6.6-W6.1-P4.57-LS9.9-TL-CW
M1, M2, M3: M2 PLATED HOLE WITH MINI HOLES
P1, P4: Header-Female-2.54_1x8; HDR-TH_8P-P2.54-V-F-1
P2: Header-Male-2.54_1x10; HDR-TH_10P-P2.54-V-M-1
P3: HEADER_6; HDR-M-2.54_1X6
PULL_A1: 3.3k; R0603
PULL_B1: 3.3k; R0603
PULL_I1: 3.3k; R0603
PULL_SCL1: 4.7k; R0603
PULL_SDA1: 4.7k; R0603
PWR: M2 PLATED HOLE WITH MINI HOLES
P_ENC1: Header-Female-2.54_1x5; HDR-TH_5P-P2.54-V-F
Pad_gge24965: Pad_gge24965
Pad_gge25001: Pad_gge25001
Pad_gge25037: Pad_gge25037
Pad_gge25067: Pad_gge25067
Pad_gge25094: Pad_gge25094
Pad_gge25115: Pad_gge25115
Pad_gge39070: Pad_gge39070
Pad_gge39073: Pad_gge39073
Pad_gge39076: Pad_gge39076
Pad_gge49879: Pad_gge49879
Pad_gge49948: Pad_gge49948
Pad_gge49993: Pad_gge49993
Pad_gge50014: Pad_gge50014
Pad_gge50035: Pad_gge50035
Pad_gge50056: Pad_gge50056
Pad_gge56675: Pad_gge56675
Pad_gge56678: Pad_gge56678
Pad_gge56681: Pad_gge56681
Pad_gge56738: Pad_gge56738
Pad_gge56741: Pad_gge56741
Pad_gge56744: Pad_gge56744
Pad_gge57389: Pad_gge57389
Pad_gge57392: Pad_gge57392
Pad_gge57395: Pad_gge57395
Pad_gge57743: Pad_gge57743
Pad_gge57746: Pad_gge57746
Pad_gge57749: Pad_gge57749
Pad_gge58091: Pad_gge58091
Pad_gge58094: Pad_gge58094
Pad_gge58097: Pad_gge58097
Pad_gge58325: Pad_gge58325
Pad_gge58328: Pad_gge58328
Pad_gge58331: Pad_gge58331
Pad_gge58361: Pad_gge58361
Pad_gge59666: Pad_gge59666
Pad_gge59669: Pad_gge59669
Pad_gge60145: Pad_gge60145
Pad_gge60148: Pad_gge60148
Pad_gge60151: Pad_gge60151
Pad_gge60328: Pad_gge60328
Pad_gge60331: Pad_gge60331
Pad_gge60334: Pad_gge60334
Pad_gge60337: Pad_gge60337
Pad_gge60853: Pad_gge60853
Pad_gge60856: Pad_gge60856
Pad_gge60859: Pad_gge60859
Pad_gge60862: Pad_gge60862
Pad_gge75108: Pad_gge75108
Pad_gge75111: Pad_gge75111
Pad_gge75114: Pad_gge75114
Pad_gge85978: Pad_gge85978
Pad_gge85981: Pad_gge85981
Pad_gge85984: Pad_gge85984
Pad_gge90416: Pad_gge90416
Pad_gge90419: Pad_gge90419
Pad_rep9: Pad_rep9
Pad_rep11: Pad_rep11
R1, R6, R7: 4.7k; R0603
R8, R9: 75k; R0603
R10: 47k; R0603
R11: 4.7kΩ; R0603
RCS1, RCS2, RCS3, RCS4: RESISTOR-SMD-1206
R_DV1: 47k; R0603
R_DV2: 4.7k; R0603
U1, U5: INA240A1PWR; TSSOP-8_L4.4-W3.0-P0.65-LS6.4-BL
U2: DRV8320HRTVT; WQFN-32_L5.0-W5.0-P0.50-TL-EP
U8, U9: BSZ0901NSATMA1; DFN-8_L3.3-W3.3-P0.65-BL-2
UB1, UB2: BSZ0901NSATMA1; DFN-8_L3.3-W3.3-P0.65-BL-2
UC1, UC2: BSZ0901NSATMA1; DFN-8_L3.3-W3.3-P0.65-BL-2

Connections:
0.1_VCC: Pad_gge85981.0.1_VCC, R_DV1.2, R_DV2.1
3.3V: P4.4, Pad_gge39073.2
+5V: P4.5, Pad_gge39076.2
C1_OUT: Pad_gge56741.2, U1.8
C2_OUT: Pad_gge56678.2, U5.8
C6_2: C6.2, U2.2
C7_1: C7.1, U2.32
C7_2: C7.2, U2.1
D1_1: D1.1, R1.1
D2_2: D2.2, R7.2
DVDD: C4.2, D2.1, R6.2, U2.24
ENABLE: Pad_gge57392.2, R11.2, U2.22, U2.26, U2.28, U2.30
ENC_A: PULL_A1.2, P_ENC1.1, Pad_gge60331.2
ENC_A_SP: PULL_A1.1, Pad_gge25067.1
ENC_B: PULL_B1.2, P_ENC1.2, Pad_gge60148.2
ENC_B_SP: PULL_B1.1, Pad_gge25094.1
ENC_I: PULL_I1.2, P_ENC1.3, Pad_gge60856.2
ENC_I_SP: PULL_I1.1, Pad_gge25115.2
GHA: Pad_gge49879.5, U2.5, U9.4
GHB: Pad_gge50014.5, U2.12, UB1.4
GHC: Pad_gge50035.5, U2.13, UC1.4
GLA: Pad_gge49948.5, U2.7, U8.4
GLB: Pad_gge49993.5, U2.10, UB2.4
GLC: Pad_gge50056.5, U2.15, UC2.4
GND: C1.1, C4.1, C5.1, C9.2, C10.2, CB1.2, CB2.1, CB3.2, CBYP3.1, CBYP4.1, CL1.2, CN1.1, CN1.7, CN1.8, CN2.1, CN2.5, CN2.6, D1.2, GND.1, L1.2, P2.4, P4.6, P4.7, P_ENC1.4, R8.2, R9.2, R10.2, R11.1, R_DV2.2, U1.4, U1.7, U2.8, U2.9, U2.16, U2.23, U2.31, U2.33, U5.4, U5.7, U8.1, U8.2, U8.3, UB2.1, UB2.2, UB2.3, UC2.1, UC2.2, UC2.3
IDRIVE: R9.1, U2.19
INHA: Pad_gge58328.2, U2.25
INHB: Pad_gge58094.2, U2.27
INHC: Pad_gge57746.2, U2.29
L1_1: L1.1, Pad_gge90419.2
MODE: R10.1, U2.18
NFLT: Pad_gge59669.2, R6.1, R7.1, U2.17
PIN2: P1.6, Pad_gge60145.2
PIN3: P1.5, Pad_gge57743.2, Pad_gge60334.2
PIN4: CN1.6, P1.4, Pad_gge60859.2
PIN5: P1.3, Pad_gge57749.2
PIN6: P1.2, Pad_gge58361.2
PIN7: P1.1, Pad_gge57389.2
PIN8: P2.10, Pad_gge57395.2
PIN9: P2.9, Pad_gge58091.2
PIN10: P2.8, Pad_gge58097.2
PIN11: CN1.3, P2.7, Pad_gge58325.2, Pad_gge60862.2
PIN12: CN1.4, P2.6, Pad_gge60337.2
PIN13: CN1.5, P2.5, Pad_gge58331.2, Pad_gge60853.2
PINA0: P3.1, Pad_gge56675.2
PINA1: P3.2, Pad_gge56681.2
PINA2: P3.3, Pad_gge56738.2
PINA3: P3.4, Pad_gge56744.2, Pad_gge59666.2, Pad_gge85978.2
PINA4: P3.5, Pad_gge60328.2, Pad_gge85984.2
PINA5: P3.6, Pad_gge60151.2
SCL: CN2.4, P2.1, PULL_SCL1.2
SCL_SP: PULL_SCL1.1, Pad_gge75108.2
SDA: CN2.3, P2.2, PULL_SDA1.2
SDA_SP: PULL_SDA1.1, Pad_gge75114.2
SHA: RCS2.1, RCS4.1, U1.2, U2.6, U8.5, U9.1, U9.2, U9.3
SHA_CS: M3.1, RCS2.2, RCS4.2, U1.3
SHB: M2.1, U2.11, UB1.1, UB1.2, UB1.3, UB2.5
SHC: RCS1.1, RCS3.1, U2.14, U5.2, UC1.1, UC1.2, UC1.3, UC2.5
SHC_CS: M1.1, RCS1.2, RCS3.2, U5.3
VCC: C1.2, C5.2, C6.1, C9.1, C10.1, CB1.1, CB2.2, CB3.1, PWR.1, Pad_gge90416.VCC, R1.2, R_DV1.1, U2.3, U2.4, U9.5, UB1.5, UC1.5
VDD: CBYP3.2, CBYP4.2, CN1.2, CN2.2, P_ENC1.5, Pad_gge24965.2, Pad_gge25001.2, Pad_gge25037.2, Pad_gge39070.2, Pad_gge75111.2, U1.5, U1.6, U5.5, U5.6
VDS: R8.1, U2.20
VIN: CL1.1, L1.3, P4.8

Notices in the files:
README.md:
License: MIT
